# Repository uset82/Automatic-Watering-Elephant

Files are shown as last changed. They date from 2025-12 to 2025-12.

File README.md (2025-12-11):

# 🐘 Automatic Watering Elephant





> A dual-microcontroller autonomous plant watering system with a rotating table mechanism

**Course:** ADA525 - HW/SW System Design (Western Norway University of Applied Sciences)  
**Author:** Carlos Carpio  
**Date:** December 2025

---

## 📋 Overview

The **Automatic Watering Elephant** is an IoT plant care system that autonomously waters two avocado plants using a rotating table mechanism. It features a decorative elephant figurine with a detachable "hat" that houses the sensor electronics.

### ✨ Features

- 🔄 **Rotating table** with 3D-printed gear mechanism
- 🌡️ **Environmental monitoring** (temperature, humidity, soil moisture)
- 📺 **OLED display** for real-time status
- 🎮 **Position learning** - set plant positions with buttons
- 💧 **Automatic watering** with pump control
- 📊 **Web-based serial plotter** for signal visualization

---

## 🏗️ Architecture

```
┌─────────────────────┐     GPIO Signals      ┌─────────────────────┐
│   RP2350-Zero       │◄────────────────────►│    Arduino Uno      │
│   "The Brain"       │   TABLE_READY        │    "The Muscle"     │
│                     │   WATER_DONE         │                     │
│  • DHT11 Sensor     │                      │  • Stepper Motor    │
│  • Soil Moisture    │                      │  • Pump Relay       │
│  • OLED Display     │                      │  • Button Controls  │
└─────────────────────┘                      └─────────────────────┘
```

---

## 🛠️ Hardware Requirements

| Component | Quantity | Purpose |
|---|---|---|
| Arduino Uno | 1 | Motor & pump control |
| RP2350-Zero | 1 | Sensors & display |
| 28BYJ-48 Stepper | 1 | Table rotation |
| ULN2003 Driver | 1 | Stepper driver |
| SSD1306 OLED | 1 | Status display |
| DHT11 | 1 | Temperature/humidity |
| Soil Moisture Sensor | 1 | Soil monitoring |
| 5V Relay Module | 1 | Pump control |
| Mini Water Pump | 1 | Water delivery |
| Push Buttons | 3 | User controls |

---

## 📁 Project Structure

```
mesarota/
├── rotatingTable/          # Arduino Uno firmware
│   ├── src/main.cpp        # Motor, buttons, pump control
│   └── platformio.ini      # PlatformIO config
│
├── elefante/               # RP2350-Zero firmware  
│   ├── src/main.cpp        # Sensors, OLED, communication
│   └── platformio.ini      # PlatformIO config
│
├── PLOTTER ELEFANTE/       # Web-based serial plotter
│   ├── src/main.js         # Dual-port serial connection
│   ├── index.html          # UI layout
│   └── package.json        # Node dependencies
│
├── WIRING_GUIDE.md         # Detailed wiring instructions
└── README.md               # This file
```

---

## 🚀 Getting Started

### Prerequisites

- [PlatformIO](https://platformio.org/install) (VS Code extension recommended)
- [Node.js](https://nodejs.org/) (for the plotter)

### Installation

1. **Clone the repository:**
   ```bash
   git clone https://github.com/YOUR_USERNAME/automatic-watering-elephant.git
   cd automatic-watering-elephant
   ```

2. **Upload Arduino firmware:**
   ```bash
   cd rotatingTable
   pio run --target upload
   ```

3. **Upload RP2350 firmware:**
   ```bash
   cd ../elefante
   pio run --target upload
   ```

4. **Run the serial plotter (optional):**
   ```bash
   cd "../PLOTTER ELEFANTE"
   npm install
   npm run dev
   ```

---

## 🎮 Usage

### Position Learning Mode

1. **Power on** both controllers
2. **Hold Button A** → Rotate table clockwise
3. **Click Button A** → Save Position A (LED blinks 2x)
4. **Hold Button B** → Rotate table counter-clockwise
5. **Click Button B** → Save Position B (LED blinks 3x)

### Automatic Watering Cycle

After both positions are saved:
1. Table moves to **Position A** → Waters for 3 seconds
2. Table moves to **Position B** → Waters for 3 seconds
3. System enters **Sleep Mode**

### Reset

Press the **Reset Button** anytime to restart position learning.

---

## 📊 Serial Plotter

The web-based plotter displays real-time sensor data:

- **Temperature** (°C)
- **Humidity** (%)
- **Soil Moisture** (ADC)
- **Motor Position** (degrees)
- **Pump Status** (ON/OFF)

Access at `http://localhost:5173` after running `npm run dev`.

---

## 📷 Gallery

*Add images of your project here!*

---

## 📄 License

This project is open source and available under the [MIT License](LICENSE).

---

## 🙏 Acknowledgments

- **Professor Frikk Fossdal** - Course instructor & [Read Serial Plot tool](https://experiment.frikkfossdal.com/)
- **Western Norway University of Applied Sciences** - ADA525 Course
- **MakerWorld** - Image-to-3D tool for elephant figurine

---

*Made with ❤️ for ADA525 HW/SW System Design*

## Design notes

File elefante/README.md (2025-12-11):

# RP2350-Zero - Sensor Hub & Display

This firmware handles environmental sensors (DHT11, soil moisture) and the OLED display.

## Hardware Connections

| Pin | Function |
|-----|---|
| GP4 | OLED SDA |
| GP5 | OLED SCL |
| GP6 | DHT11 Data |
| GP10 | TABLE_READY ← Arduino (via voltage divider!) |
| GP11 | WATER_DONE → Arduino |
| GP26 | Soil Moisture Sensor (ADC) |

## Build & Upload

```bash
cd elefante
pio run --target upload
```

> ⚠️ If upload fails, hold BOOTSEL while plugging in USB.

## Serial Output (115200 baud)

Outputs: `Temp: 25.5 Humidity: 45 Pot: 2100 Motor: 0 OFF`

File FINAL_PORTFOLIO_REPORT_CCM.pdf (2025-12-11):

## Automatic Plant Watering Elephant with Rotating Table

## ADA525 Final Portfolio Report

Author: Carlos Carpio Date: December 2025 Institution: HVL - Western Norway University of Applied Sciences Course: ADA525 - Advanced Data Acquisition

## Introduction

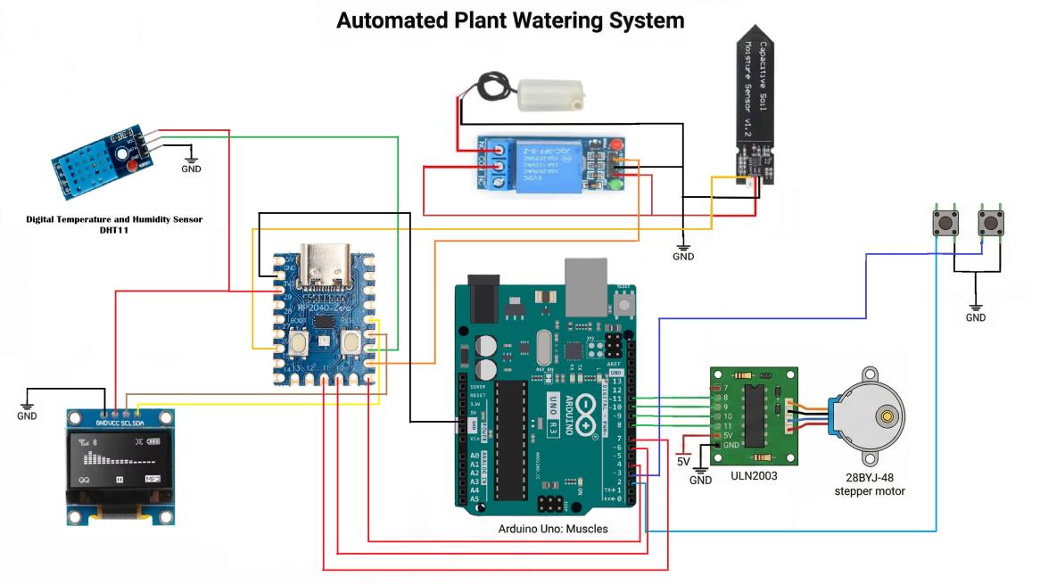
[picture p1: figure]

Visualization of the Automatic Watering Elephant project, showing the integration of nature and technology in a home plant care system.

Q0. Project Description

ELEPHANT AND DETACHABLE HAT CONCEPT

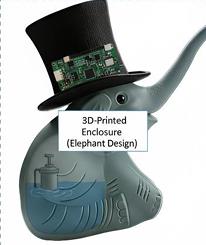
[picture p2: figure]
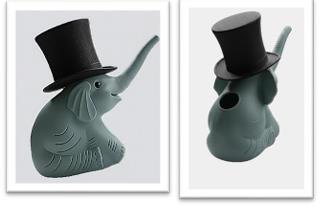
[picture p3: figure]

Figure 1: Concept art for the “Watering Elephant” design, featuring a decorative elephant figurine with a detachable hat that houses the electronics. The playful design makes the functional watering system blend naturally into a home environment. Generated using Google Gemini AI, nanoBanana.
The Automatic Watering Elephant is a dual-microcontroller plant care system that autonomously waters two avocado plants from Peruvian seeds using a rotating table mechanism. The system is designed to solve a real problem: maintaining healthy plants while traveling or during busy periods.
Why I wanted to make it: Growing avocado plants from seed requires consistent moisture levels. After losing several promising seedlings to irregular watering during travel, I was motivated to create a system that could reliably care for my plants without daily intervention. The project also presented an exciting opportunity to integrate digital fabrication, embedded systems, and inter-device communication.
Key Features:
1. Dual-Controller Architecture: RP2350-Zero handles sensing and decision-making (“Brain”), Arduino Uno controls mechanical rotation (“Muscles”)
2. Single Sensor for Multiple Plants: A rotating table brings each plant to the watering position, optimizing hardware usage
3. Capacitive Soil Moisture Sensing: Monitors soil moisture with 12-bit ADC resolution
4. Environmental Monitoring: DHT11 sensor tracks temperature and humidity
5. Pendulum Motion: The table swings back and forth (not continuous rotation) to prevent cable tangling
6. Flexible Position Learning: User can set plant positions in any order using teach-mode buttons
7. OLED Display: Real-time status visualization

Project Evolution Timeline

This project evolved through multiple phases during the ADA525 course:

Phase | Date | Focus | Key Learning
Initial Concept | Sep-Oct 2025 | Single-plant Arduino prototype | Basic pump control, sensor reading
Intermediate Report | Nov 2025 | RP2350-only design with rotating table | Power management challenges, motor interference
Final System | Dec 2025 | Dual-controller architecture | Inter-MCU communication, voltage level shifting

Evolution Highlights:
- Started with a simple Arduino-only watering system for one plant
- Teacher feedback pushed for more complexity → added mechanical rotation
- Power instability in RP2350-only design led to dual-controller architecture
- Cable tangling issue led to pendulum motion innovation
- Component failures taught importance of quality parts and debugging methodology The final system represents the culmination of lessons learned from each iteration, where early failures directly informed the robust design choices in the production version.
Q1. Core Workflow

The system workflow operates as follows:
User Interaction:
1. User powers on the system
2. LED illuminates indicating Learning Mode
3. User HOLDS Button A/B to manually rotate table to first plant position
4. User CLICKS to save position (LED blinks 3×)
5. User moves to second plant and CLICKS to save (LED blinks 5×)
6. System enters autonomous Run Mode

Sensing and Processing:

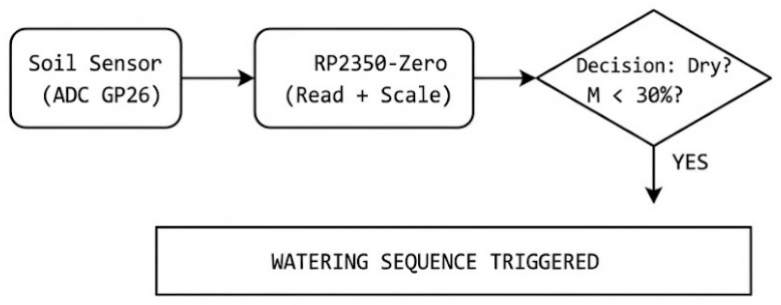
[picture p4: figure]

System Response (Handshake Protocol - Modified):
1. RP2350 sets WATER_SIGNAL = HIGH → Arduino receives on Pin 4 (Trigger)
2. Arduino rotates table to Plant 1
3. Arduino activates pump (Pin 12) for 3 seconds
4. Arduino rotates to Plant 2
5. Arduino activates pump (Pin 12) for 3 seconds
6. System enters sleep mode (waiting for next trigger or reset)

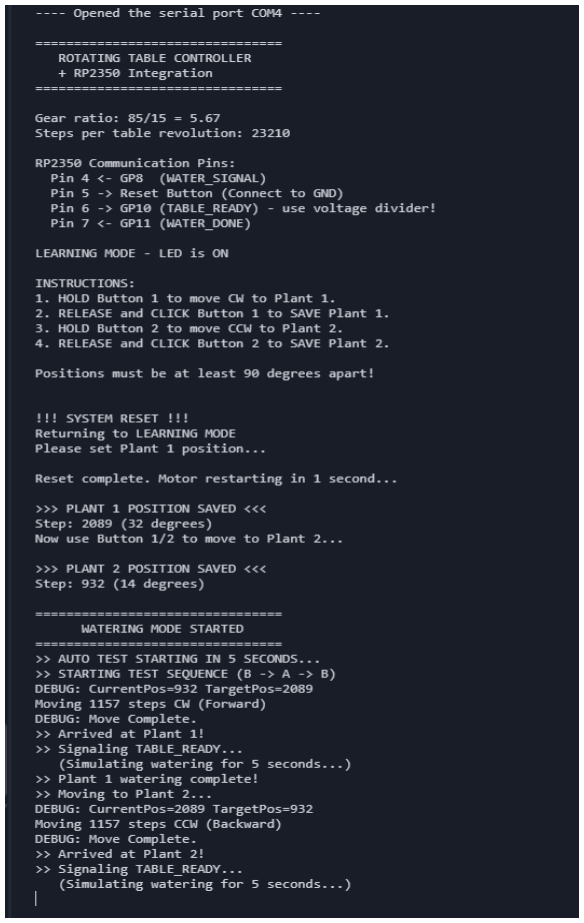
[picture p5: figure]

Figure 2: Screenshot of the Arduino Serial Monitor during a complete watering cycle. The output demonstrates the flexible position learning system. The users can set positions in any order (A→B or B→A) depending on the motor’s starting position. After both positions are saved (with LED blink feedback), the simulation sequence automatically begins: the table moves to Position A, waters for 3 seconds, moves to Position B, waters again, and enters sleep mode.
NOTE: Pump control was moved from RP2350 to Arduino (Pin 12) to overcome GPIO latching issues on the prototype board. The RP2350 retains the role of “Brain” (Sensing), while Arduino acts as “Muscle” (Motion & Action).

## System Implementation

Digital Fabrication Focus
Q2. CAD & 3D Printing Integration
The Elephant Figurine Evolution:
From idea to 3D modeling, I started by generating the elephant concept image in Google Gemini AI and then used MakerWorld’s MakerLab “Image to 3D” tool to turn it into a 3D mesh. I first imported this mesh into Fusion 360 to inspect and split the geometry, but the dense mesh was difficult to handle there, so I moved the project to Blender.
In Blender, I used the Boolean modifier to subtract an inner shape from the elephant, creating a clean internal cavity and turning the solid model into a hollow “elephant kettle” that could house the electronics. Blender also helped me fix errors and rebuild the imperfections from the AI-generated mesh. In the end, I spent more time repairing than building, but that taught me valuable lessons as an engineer about real-world challenges and different approaches to problem-solving.

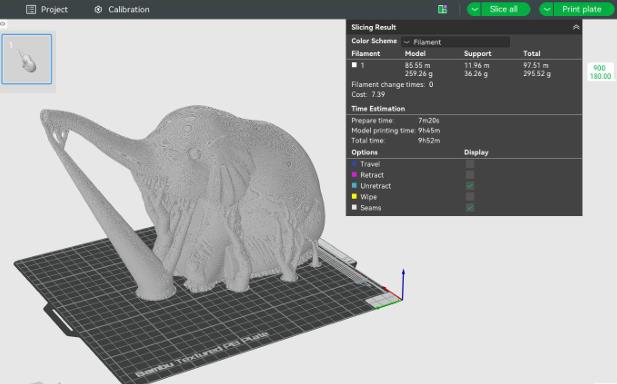
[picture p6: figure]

Blender Mesh Repair Process

Figure 3: When I import a model from Blender into Bambu Studio it often shows up much smaller, because the two programs use different unit scales. If I do not fix the size right away, later edits and slicing go wrong, and I kept running into the same error after shrinking the model. Before scaling to real size I first cut the hat away from the elephant in Bambu Studio, so I can scale and align each part separately with better precision.

The Rotating Table Mechanism:
The rotating table mechanism required custom gears designed in CAD and manufactured using 3D printing:

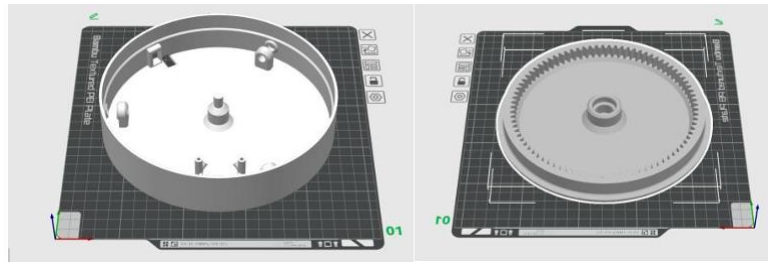
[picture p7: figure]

3D Model of Rotating Table

Figure 4: CAD model of the rotating display table designed in Fusion 360. The design features an integrated ring gear mechanism that meshes with a small driver gear attached to the stepper motor, providing smooth and precise rotation.
Design Evolution:
Version | Design | Issue | Solution
V1 | Single gear, direct drive | Insufficient torque | Added gear reduction
V2 | 15:85 tooth ratio | Gear slippage | Redesigned tooth profile
V3 (Final) | Optimized spur gear + ring gear | N/A | Successful

COMPONENTS DESIGNED AND PRINTED:
- Small Driver Gear: 15-tooth spur gear (orange PLA), press-fit to motor shaft

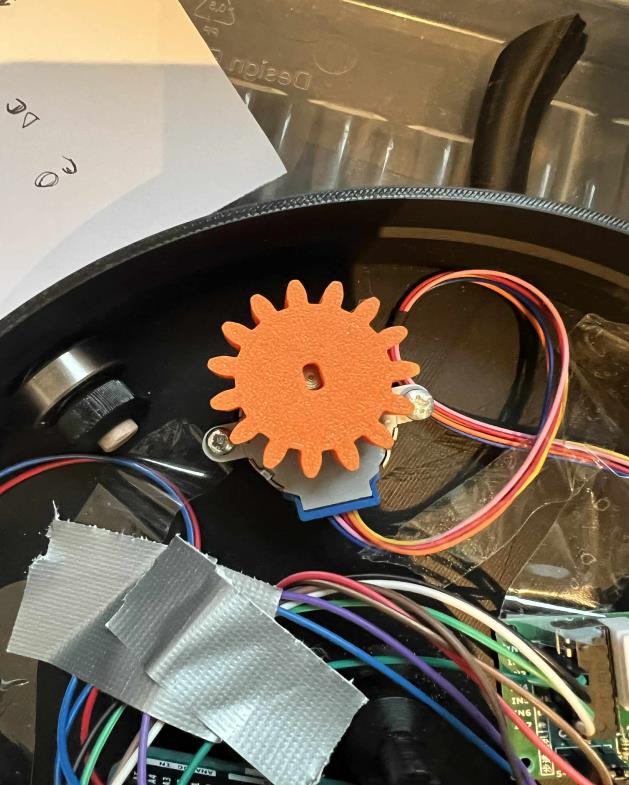
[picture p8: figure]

Figure 5: The 15-tooth driver gear printed in orange PLA, designed to press-fit onto the 28BYJ-48 motor’s asymmetric shaft.

- Large Ring Gear: 85-tooth internal ring gear (white PLA), integrated into table base

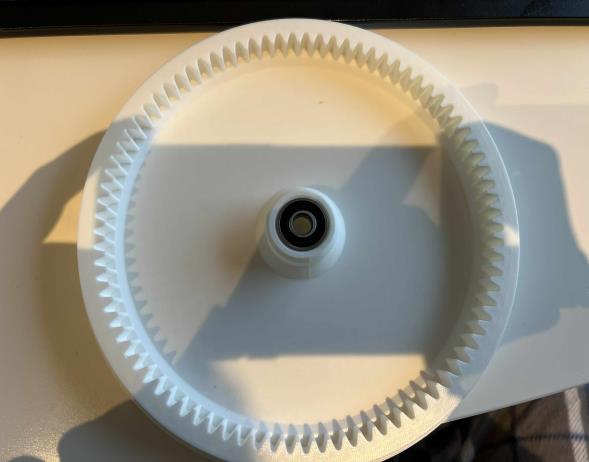
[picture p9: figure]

Figure 6: The 85-tooth ring gear printed in white PLA, which forms the base of the rotating table and provides the 5.67:1 gear reduction.

Gear Ratio Calculation:

Gear Ratio =

85
15 = 5.67

This provides:
- Speed reduction: Motor runs 5.67× faster than table rotation
- Torque multiplication: Table receives 5.67× motor torque
- Precision: 23,210 steps per table revolution (0.0155° resolution) Tools Used:
- Fusion 360 for gear modeling
- Cura slicer for print preparation
- Creality Ender 3 printer (0.2mm layer height, 20% infill)
Q3. Fabrication Challenges
Challenge 1: Gear Backlash Early prints exhibited significant play between meshing teeth, causing positioning inaccuracy.
Solution: Adjusted tooth clearance in CAD by reducing the module parameter by 0.1mm. Required 3 print iterations to achieve acceptable fit.
Challenge 2: Motor Shaft Coupling The 28BYJ-48 motor has an asymmetric shaft that was difficult to model accurately.
Solution: Created a test coupler with incrementally different hole shapes, then updated the main gear design based on best-fit results.
Challenge 3: Ring Gear Warping The large ring gear (120mm diameter) exhibited warping during printing due to uneven cooling.
Solution: Enabled heated bed adhesion rim and printed at reduced speed (30mm/s) for first 5 layers.

Physical Computing Focus
Q4. Hardware Integration

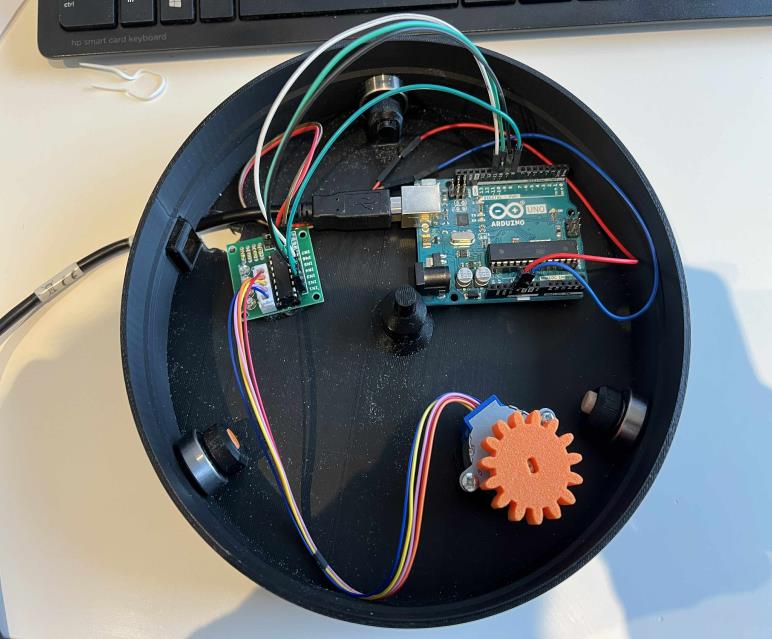
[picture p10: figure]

Internal Electronics Layout

Figure 7: Internal view of the electronics assembly showing the RP2350-Zero microcontroller, relay module, and sensor connections. The compact layout fits within the elephant figurine’s detachable hat.
The system incorporates multiple physical computing elements across two microcontrollers:
RP2350-Zero (Sensor Hub & Brain):
Component | Purpose | Connection | Justification
Capacitive Soil Sensor | Moisture detection | GP26 (ADC) | Corrosion-resistant, long-term reliability
DHT11 | Temp/Humidity | GP6 (Digital) | Low cost, sufficient accuracy for plant care
SSD1306 OLED | Status display | I2C (GP4/5) | Low power, always-on visibility
Relay Module | Pump control | GP7 | Isolates high-current load from MCU

Arduino Uno (Motor Controller + Pump):

Component | Purpose | Connection | Justification
28BYJ-48 Stepper | Table rotation | Pins 8-11 | High torque, low cost, easy control
ULN2003 Driver | Current amplification | Pins 8-11 | Matches motor requirements exactly
Push Buttons ×3 | Position A, B, Reset | Pins 2, 3, 5 | Simple, reliable user input
Relay Module | Pump control | Pin 12 | Arduino-direct control for reliability

Final Implementation: During integration testing, RP2350 GPIO issues led to moving pump control directly to Arduino Pin 12. This simplified the system and improved reliability while maintaining all functionality.

OLED Display

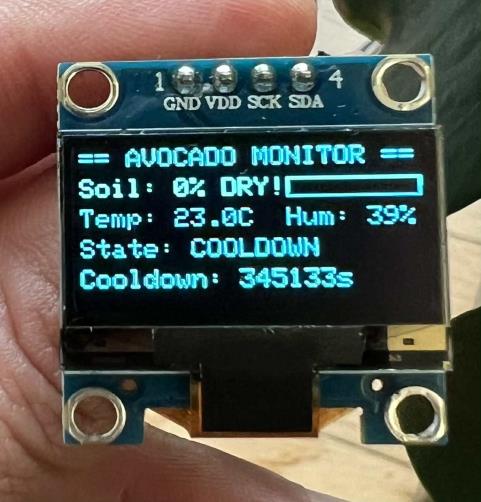
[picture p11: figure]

Figure 8: The SSD1306 OLED display (128×64 pixels) showing real-time system status. The display provides immediate visual feedback including current state (Idle/Watering), temperature, humidity, and soil moisture readings. Connected via I2C to the RP2350-Zero (GP4/GP5), this low-power display remains always-on for easy monitoring.
Key Code Snippet - Stepper Control:

// Half-step sequence for smoother motion (8 phases) const int halfStepSequence[8][4] = {
{1,0,0,0}, {1,1,0,0}, {0,1,0,0}, {0,1,1,0}, {0,0,1,0}, {0,0,1,1}, {0,0,0,1}, {1,0,0,1}
};

void stepMotor(bool clockwise) {
stepPhase += clockwise ? 1 : -1;
if (stepPhase >= 8) stepPhase = 0;
if (stepPhase < 0) stepPhase = 7;

digitalWrite(IN1, halfStepSequence[stepPhase][0]);

// ... IN2, IN3, IN4
delay(stepDelay); // 1ms for maximum speed }
Q5a. Data Acquisition Strategy
Soil Moisture Calibration: The capacitive sensor outputs analog voltage inversely proportional to moisture. Calibration was performed by:
1. Recording ADC value in air: R_dry ≈ 3000
2. Recording ADC value in water: R_wet ≈ 1200
3. Applying linear interpolation:

M = 100 × (1 −
R − Rwet

Rdry − Rwet)

Setting the watering threshold at 30% moisture proved optimal after testing. Lower thresholds (20%) caused stress-visible wilting; higher thresholds (40%) led to overwatering and root rot risk. Avocado plants (Persea americana) prefer to dry out between waterings, so a 4-5 day cooldown period between watering cycles was implemented to prevent overwatering.

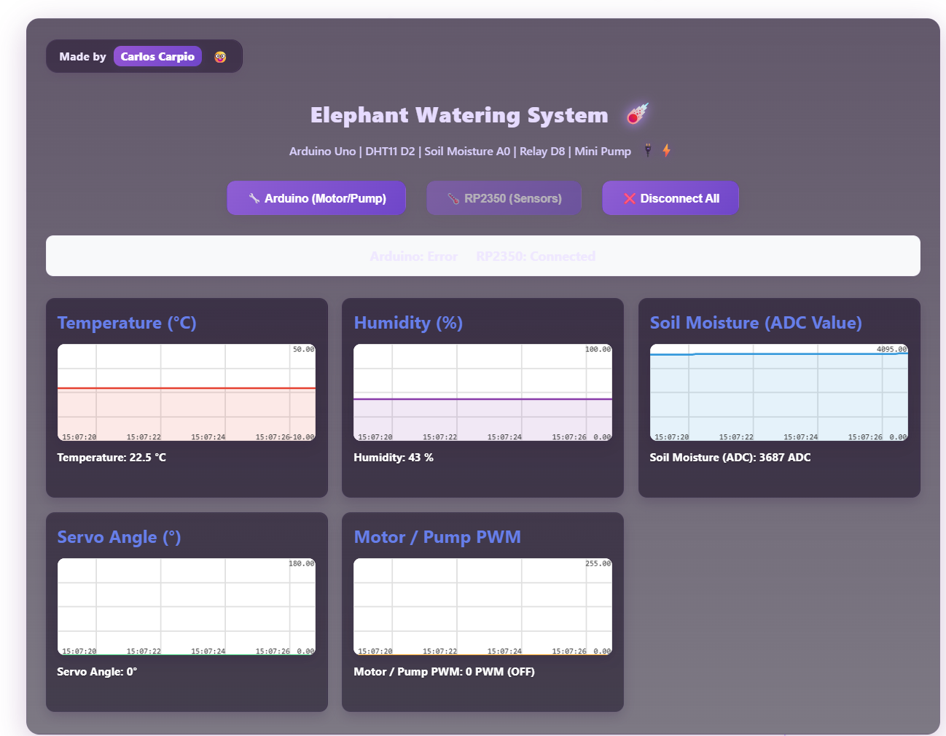
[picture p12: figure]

Sensor Data Graph

Figure 9: Real-time visualization of sensor data using the "Read Serial Plot" tool (https://experiment.frikkfossdal.com/content/guides/readserial_plot.md) created by Professor Frikk Fossdal. This graph demonstrates how the soil moisture ADC values can be monitored live during development and calibration. The tool streams serial output directly into a graphical interface, making it easy to identify sensor behavior patterns and set appropriate thresholds.
Position Tracking: The Arduino maintains a step counter that wraps at 23,210 (one full revolution). When saving positions, the current step value is stored, enabling precise return navigation using the shortest-path algorithm.
Q5b. Integration Challenges
Challenge 1: Voltage Level Mismatch The RP2350 operates at 3.3V logic; Arduino Uno at 5V. Direct connection from Arduino Pin 6 to RP2350 GP10 risked damaging the Pico. Solution: Implemented voltage divider (1kΩ + 2kΩ):

Vout = 5V ×

2000
3000 = 3.33V

Voltage Divider Wiring Diagram:

┌─────────────────────────────────────┐
│ | VOLTAGE DIVIDER | │
└─────────────────────────────────────┘
ARDUINO UNO | RP2350-ZERO
┌───────────┐ | ┌───────────┐
│ | │ | │ | │
│ | Pin 6 | │────[1kΩ]────┬────[2kΩ]──── │ | GND | │
│ (OUTPUT) │ | │ | │ | │
│ | │ | │ | │ | │
│ | GND | │─────────────┼──────────────│ | GND | │
│ | │ | │ | │ | │
└───────────┘ | │ | │ | GP10 | │
│ | │ (INPUT) │
└──────────────│ | │
└───────────┘
CAUTION. Never connect Arduino 5V outputs directly to RP2350 GPIO pins! The RP2350 GPIO is rated for 3.3V maximum. Connecting 5V directly will damage or destroy the pin. Always use a voltage divider for signals going FROM Arduino TO RP2350.
Challenge 2: Button Debouncing Initial implementation registered multiple button presses due to mechanical bounce.
Solution: Added 200ms debounce delay and separate timers for position buttons vs. reset button.
Challenge 3: Motor Speed vs. Torque Trade-off Too fast (1ms delay): Motor skipped steps under load. Too slow (5ms delay): Watering cycle took too long.
Solution: Settled on 1ms delay after testing showed the gear reduction provided sufficient torque even at maximum speed.
Challenge 4: Power Supply Voltage Drop (Critical) When both motors (water pump and stepper motor) were connected to the same power supply, the stepper motor stopped working intermittently. Even after adding a 2200μF decoupling capacitor and testing with an L293D driver, the problem persisted.
Root Cause Analysis:
- The water pump draws a large inrush current when starting
- This caused the shared power rail voltage to drop significantly
- The L293D driver adds an additional 1.2-2V voltage drop
- Combined effect: stepper driver received insufficient voltage to function Solution: Separated the system into two independent 9V battery supplies:

Battery | Powers | Reason
9V Battery #1 | Arduino Uno + Stepper Motor + ULN2003 | Isolated motor power prevents interference
9V Battery #2 | RP2350 + Pump + Sensors (OLED, DHT11) | Pump surges don’t affect logic circuits

Critical: Both batteries share a common ground to maintain signal integrity for the handshake protocol.
This dual-battery configuration completely eliminated the voltage instability issues.

Challenge 5: Defective Low-Cost Hardware (The “AliExpress Lesson”)

I bought a very cheap RP2350 Zero board from AliExpress to use as the main controller. It behaved unpredictably when driving motors, even with simple code.

- Symptoms: GPIO pins got stuck LOW, uploads worked but the program did not run, and motor control was unstable.
- Tried fixes: Added big decoupling capacitors, used separate power supplies, and rewrote the code over two very long debugging days.
- Result: The board was simply not reliable for heavy work, most likely due to poor internal power design or low manufacturing quality.

Lesson learned: Cheap boards may save money but can cost many hours of debugging. The dual controller setup saved the project, since the reliable Arduino could take over when the “smart” but weak RP2350 Zero failed.

Integration and Synthesis
Q6. Mechanical + Electronic Integration

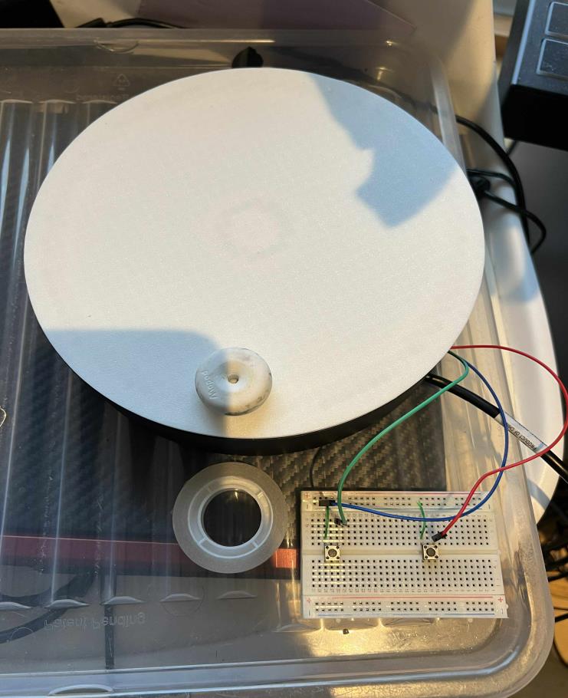
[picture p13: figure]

Final Assembled Rotating Table

Figure 10: The fully assembled rotating table mechanism showing the 3D-printed ring gear, stepper motor mount, and plant positioning area. The pendulum motion design allows back-and-forth movement without cable tangling.
Integrating the 3D-printed gears with the electronic control system required careful consideration:
Physical Constraints:
- Motor mount had to align the gears within 0.5 mm
- Wires had to be routed away from moving parts
- The sensor on the table needed flexible cables

These limits killed my original idea of 360 degree continuous rotation, because the cables kept tangling in early tests. I redesigned the system to use a pendulum style motion instead and rewrote the state machine logic, which made the whole setup more robust.

Design Considerations:
1. Cable Management: The pendulum motion (back-and-forth) was specifically chosen to prevent water hose and cable tangling that would occur with continuous rotation
2. Gear Alignment: Added adjustment slots in motor mount to fine-tune gear mesh after assembly
3. Weight Distribution: Positioned electronics below the table to lower center of gravity

Q7. Iterative Process

Prototype Version 1 - Single Plant (Too Simple):
- Arduino Uno only, no rotating table
- Single plant with direct pump connection
- Manual button trigger for watering
- Feedback: Teacher said “too simple” - needed more complexity to demonstrate embedded systems skills
- Decision: Add mechanical rotation to water multiple plants with single pump Prototype Version 2 - Integrated Elephant (RP2350 Only):
- RP2350-Zero as the sole controller (no Arduino)
- All components housed inside the elephant figurine’s hat
- RP2350 directly driving stepper motor via ULN2003
- Capacitive soil sensor for moisture detection
- Water pump controlled via relay
- Problem: Power instability when pump and stepper shared supply - stepper stopped working during pump activation
- Problem: Even with 2200μF capacitor and L293D driver, voltage drops persisted
- Decision: Split system into two controllers to isolate motor power domains Prototype Version 3 - Final Dual-Controller System:
- Separated into two controllers: RP2350 (Brain) + Arduino Uno (Muscles)
- Dual 9V battery power supply
- Digital handshake protocol for communication
- Pendulum motion to prevent cable tangling
- Flexible position learning (either button first)
- Full sensor suite: soil moisture, DHT11, OLED display

Major Challenge: Cheap Component Failures
A significant time delay occurred due to defective components purchased from low-cost suppliers:
Failed Component | Symptom | Resolution
Stepper Motor #1 | Erratic movement, missed steps | Replaced
Stepper Motor #2 | Coil burned, no response | Replaced
DHT11 Sensor | Constant “NaN” readings | Replaced with known-good unit
Dupont Cables | Intermittent connections | Replaced with higher quality cables
Lesson Learned: The time “saved” buying cheap components was lost debugging phantom failures. For future projects, I would invest in quality components from reputable suppliers, especially for critical actuators.
Major Integration Problem:
Issue: When the stepper motor activated, electrical noise caused false readings on the soil moisture ADC, triggering phantom watering cycles.
Diagnosis: Used oscilloscope to observe voltage spikes on the power rail during motor steps. The ULN2003 driver’s inductive kickback was coupling into the shared ground.

Critical Evaluation and Future Scope
Q9. System Evaluation
Strengths:
- Modular dual-controller architecture enables independent testing
- Pendulum motion solves cable management elegantly
- Flexible position learning accommodates various plant arrangements
- Single sensor for multiple plants optimizes cost
Limitations:
- No persistent position storage (lost on power cycle)
- Fixed watering duration regardless of pot size
- Single moisture sensor assumes identical soil for both plants
- No remote monitoring capability

Q10. Future Improvements
Improvement | Benefit | Complexity
EEPROM position storage | Survives power cycle | Low
Custom PCB Shield | Eliminates cable mess & improves reliability | Medium
WiFi (ESP32) upgrade | Remote monitoring & control | Medium
Per-plant moisture sensors | Individualized watering | Medium
Water reservoir level sensor | Low-water alerts | Low
Machine learning moisture prediction | Anticipate watering needs | High
Solar power integration | Off-grid operation | Medium
Advancement Priority: With more time, I would first add EEPROM storage for positions (simple code change) and design a Custom PCB to replace the breadboard wiring, ensuring a cleaner and more durable system. Then, I would upgrade to ESP32 for WiFi capabilities.

## Appendix

A. Pin Configuration Summary

RP2350-Zero:

GP26 ← Soil Sensor (ADC)
GP6 | ← DHT11 Data
GP4 | → OLED SDA (I2C)
GP5 | → OLED SCL (I2C)
GP7 | → Relay Control
GP8 | → WATER_SIGNAL (to Arduino Pin 4)
GP10 ← TABLE_READY (from Arduino Pin 6, via voltage divider) GP11 → WATER_DONE (to Arduino Pin 7)
Arduino Uno:

Pin 2 ← Button A (Position)
Pin 3 ← Button B (Position)
Pin 4 ← WATER_SIGNAL (from RP2350 GP8) Pin 5 ← Button Reset
Pin 6 → TABLE_READY (to RP2350 GP10) Pin 7 ← WATER_DONE (from RP2350 GP11) Pin 8 → Motor IN1
Pin 9 → Motor IN2
Pin 10 → Motor IN3
Pin 11 → Motor IN4
B. References
1. Arduino Reference. (2025). Arduino Language Reference. https://www.arduino.cc/reference/en/
2. Raspberry Pi Foundation. (2024). RP2350 Datasheet.
3. 28BYJ-48 Stepper Motor Datasheet
4. ULN2003 Darlington Transistor Array Datasheet
5. DHT11 Humidity & Temperature Sensor Datasheet
6. PlatformIO Documentation. https://docs.platformio.org/

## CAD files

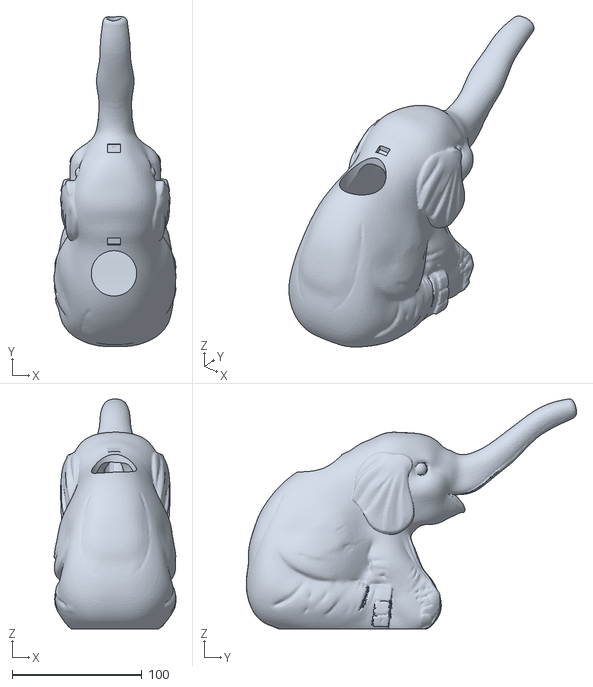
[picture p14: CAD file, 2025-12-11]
3Dmodelling/2 elephants decimated hole resizing trunk and hole fix.stl
93.9 x 254.8 x 177.3

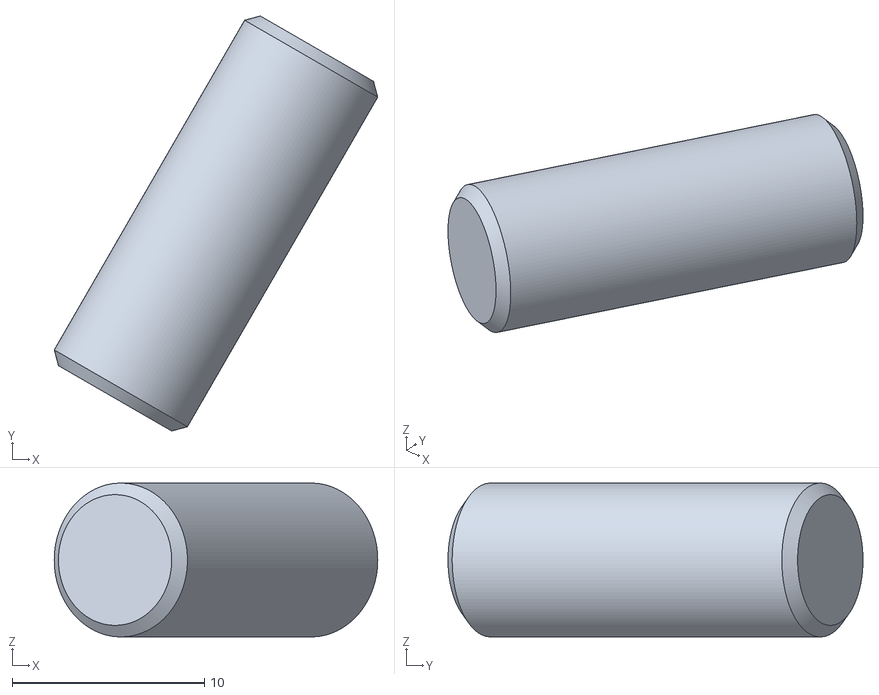
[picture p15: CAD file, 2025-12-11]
3Dmodelling/rotating table/Pin_.stl
16.8 x 21.6 x 8.00

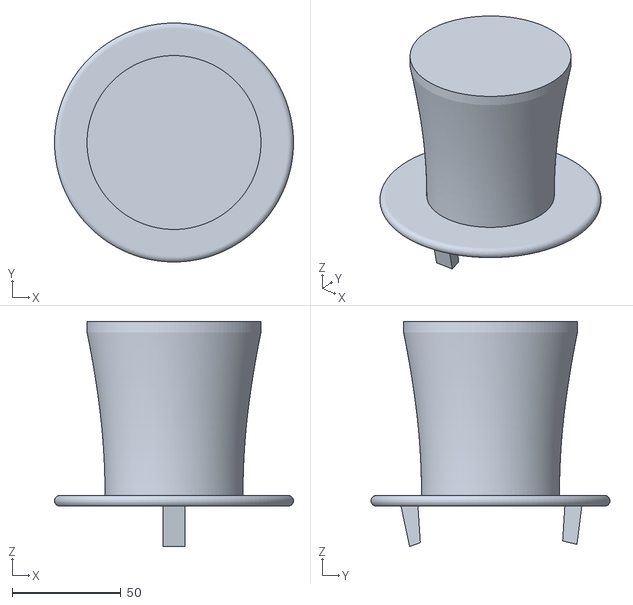
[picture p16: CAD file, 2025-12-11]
3Dmodelling/elephant hat remake.stl
110.0 x 109.9 x 103.5

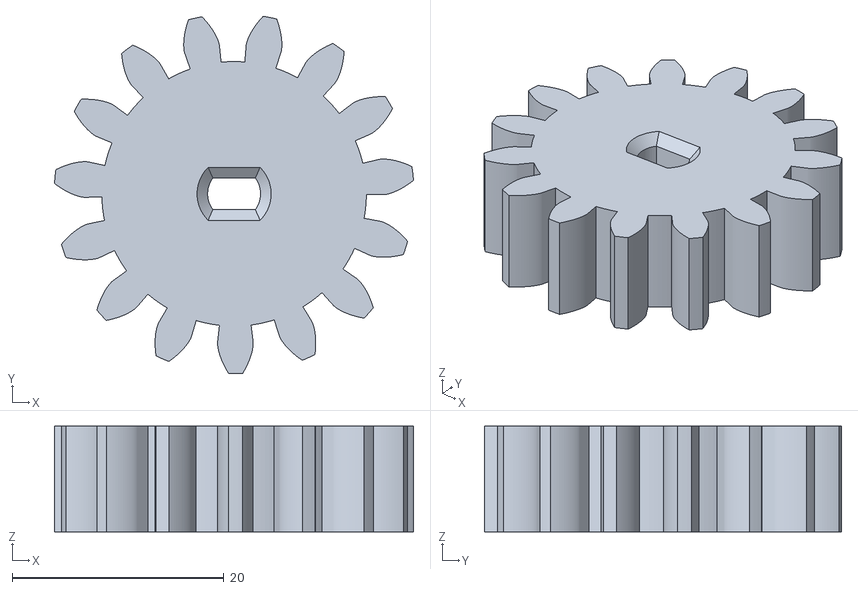
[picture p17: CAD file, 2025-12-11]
3Dmodelling/rotating table/Motor_Gear.stl
33.9 x 33.8 x 10.0

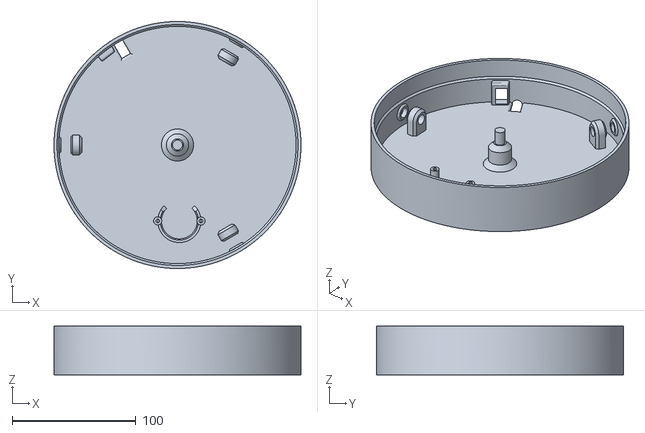
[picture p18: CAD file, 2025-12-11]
3Dmodelling/rotating table/Base.stl
200.0 x 200.0 x 39.5

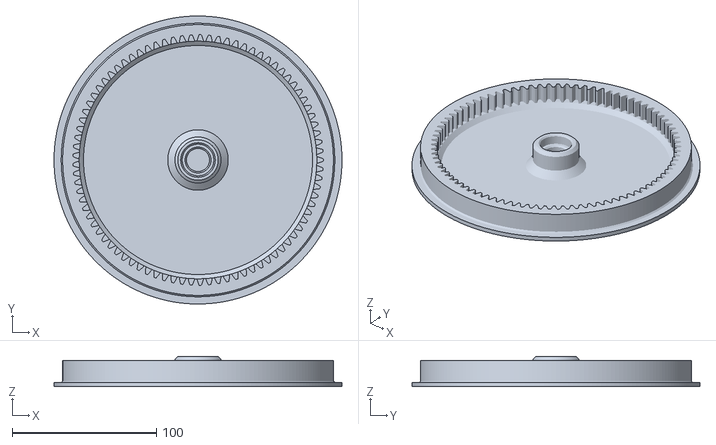
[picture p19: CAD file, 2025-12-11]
3Dmodelling/rotating table/Top_plate_.stl
200.0 x 200.0 x 21.0

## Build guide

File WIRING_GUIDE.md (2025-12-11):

# 🌱 Automatic Plant Watering System - Wiring Guide

## System Overview

This system combines:
- **RP2350-Zero**: Brain - monitors soil moisture, controls pump, communicates with Arduino
- **Arduino Uno**: Muscles - controls rotating table stepper motor
- **2 Avocado Plants** on rotating table (same pot size, same germination date)
- **1 Soil Sensor** shared for both plants (identical conditions = same watering needs)

## Power Rails

| Rail | Voltage | Components |
|---|---|---|
| Logic Rail | 3.3V | RP2350, OLED, DHT11, Soil Sensor |
| Motor Rail | 5V | Arduino Uno, Stepper Motor, Relay VCC |
| Pump Rail | 5-6V External | Water Pump (via relay) |

⚠️ **IMPORTANT**: Common GND between ALL components!

---

## RP2350-Zero Pinout

### Sensors
| Pin | Function | Component |
|-----|---|---|
| GP26 (ADC0) | Soil Moisture | Capacitive sensor (shared for both plants) |
| GP6 | DHT11 DATA | Temperature/Humidity sensor |
| GP4 | I2C SDA | OLED Display |
| GP5 | I2C SCL | OLED Display |

### Control
| Pin | Function | Component |
|-----|---|---|
| GP7 | Relay IN | Pump control (active LOW) |

### Arduino Communication
| RP2350 Pin | Direction | Arduino Pin | Signal |
|---|---|---|---|
| GP8 | OUTPUT → | Pin 4 | WATER_SIGNAL |
| GP10 | ← INPUT | Pin 6 | TABLE_READY |
| GP11 | OUTPUT → | Pin 7 | WATER_DONE |
| GND | ↔ | GND | Common Ground |

---

## Arduino Uno Pinout

### Motor Control (28BYJ-48 Stepper via ULN2003)
| Pin | Function |
|-----|---|
| Pin 8 | Motor IN1 |
| Pin 9 | Motor IN2 |
| Pin 10 | Motor IN3 |
| Pin 11 | Motor IN4 |

### Position Buttons
| Pin | Function |
|-----|---|
| Pin 2 | Button 1 - Set Plant 1 Position |
| Pin 3 | Button 2 - Set Plant 2 Position |

### RP2350 Communication
| Arduino Pin | Direction | RP2350 Pin | Signal |
|---|---|---|---|
| Pin 4 | ← INPUT | GP8 | WATER_SIGNAL |
| Pin 6 | OUTPUT → | GP10 | TABLE_READY |
| Pin 7 | ← INPUT | GP11 | WATER_DONE |
| GND | ↔ | GND | Common Ground |

---

## ⚠️ Voltage Level Shifting

The RP2350 uses **3.3V logic**, Arduino Uno uses **5V logic**.

### RP2350 → Arduino (3.3V to 5V)
✅ **Safe!** Arduino reads 3.3V as HIGH (threshold ~2.5V)
- GP8 → Pin 4 (direct connection OK)
- GP11 → Pin 7 (direct connection OK)

### Arduino → RP2350 (5V to 3.3V)
⚠️ **Needs voltage divider!** 5V will damage RP2350!

**TABLE_READY Signal (Pin 6 → GP10):**
```
Arduino Pin 6 ──[1K]──┬──[2K]── GND
                      │
                      └─── RP2350 GP10

Voltage at GP10 = 5V × (2K / (1K + 2K)) = 3.33V ✓
```

---

## Soil Moisture Sensor Wiring

Single capacitive soil moisture sensor (shared for both plants):
```
Sensor      RP2350
──────      ──────
VCC    →    3.3V
GND    →    GND
AOUT   →    GP26
```

---

## DHT11 Wiring

```
DHT11       RP2350
─────       ──────
VCC    →    3.3V
GND    →    GND
DATA   →    GP6 (internal pull-up enabled)
```

---

## OLED Display Wiring (SSD1306 128x64)

```
OLED        RP2350
────        ──────
VCC    →    3.3V
GND    →    GND
SDA    →    GP4
SCL    →    GP5
```

---

## Relay Module Wiring

```
Relay       RP2350          External Power
─────       ──────          ──────────────
VCC    →    5V (from Arduino or external)
GND    →    GND
IN     →    GP7

Relay NO    →    Pump +
Relay COM   →    External 5-6V +
Pump -      →    External GND
```

---

## Watering Sequence

```
1. RP2350 detects soil is dry (< 30% moisture)
2. RP2350 sets WATER_SIGNAL = HIGH
3. Arduino moves table to Plant 1 position
4. Arduino sets TABLE_READY = HIGH
5. RP2350 runs pump for 5 seconds
6. RP2350 sets WATER_DONE = HIGH (pulse)
7. Arduino sees WATER_DONE, moves to Plant 2 position
8. Arduino sets TABLE_READY = HIGH
9. RP2350 runs pump for 5 seconds
10. RP2350 sets WATER_DONE = HIGH (pulse)
11. Both plants watered! System enters 1 minute cooldown
```

### Signal Timing

| Signal | Duration | Purpose |
|---|---|---|
| WATER_SIGNAL | Entire watering cycle | Request watering for both plants |
| TABLE_READY | Until WATER_DONE pulse | Table is at plant position |
| WATER_DONE | 500ms pulse | Current plant watering complete |

---

## Setup Procedure

1. **Power on system** - Arduino starts in Learning Mode (LED ON)

2. **Set Plant 1 position:**
   - Wait for table to rotate to Plant 1
   - Press Button 1 (Pin 2)
   - LED blinks 3 times = Position saved

3. **Set Plant 2 position:**
   - Wait for table to rotate to Plant 2 (must be >90° from Plant 1)
   - Press Button 2 (Pin 3)
   - LED blinks 5 times = Position saved
   - System enters Watering Mode (LED OFF)

4. **Automatic operation:**
   - RP2350 monitors soil moisture
   - When soil is dry → water Plant 1 → water Plant 2 → cooldown
   - 1 minute cooldown between watering cycles

---

## Troubleshooting

| Symptom | Cause | Solution |
|---|---|---|
| Table doesn't move | No signal from RP2350 | Check GP8 → Pin 4 wire |
| RP2350 crashes | 5V on GP10 | Add voltage divider! |
| Pump doesn't run | TABLE_READY not seen | Check voltage divider output |
| Only Plant 1 watered | WATER_DONE not received | Check GP11 → Pin 7 wire |
| Soil always reads 0% | Sensor not in soil | Push sensor into soil |
| Soil always reads 100% | Wrong calibration | Adjust SOIL_DRY_VALUE/SOIL_WET_VALUE |

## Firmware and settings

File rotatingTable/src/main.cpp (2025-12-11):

#if defined(__has_include) && __has_include(<Arduino.h>)
#include <Arduino.h>
#elif !defined(__has_include) && defined(ARDUINO)
#include <Arduino.h>
#else
// Minimal Arduino stubs so clang/desktop parses without Arduino SDK
#include <chrono>
#include <thread>

#ifndef HIGH
#define HIGH 0x1
#endif
#ifndef LOW
#define LOW 0x0
#endif
#ifndef INPUT
#define INPUT 0x0
#endif
#ifndef OUTPUT
#define OUTPUT 0x1
#endif
#ifndef INPUT_PULLUP
#define INPUT_PULLUP 0x2
#endif
#ifndef LED_BUILTIN
#define LED_BUILTIN 13
#endif

inline void pinMode(int, int) {}
inline int digitalRead(int) { return HIGH; }
inline void digitalWrite(int, int) {}
inline void delay(unsigned long ms) {
  std::this_thread::sleep_for(std::chrono::milliseconds(ms));
}
inline unsigned long millis() {
  using namespace std::chrono;
  return static_cast<unsigned long>(
      duration_cast<milliseconds>(steady_clock::now().time_since_epoch())
          .count());
}

struct SerialMock {
  void begin(unsigned long) {}
  template <typename T> void print(const T &) {}
  template <typename T> void println(const T &) {}
  void println() {}
} Serial;
#endif

/*
  Rotating Table + RP2350 Pump Control

  SKIP SOIL SENSOR - Manual trigger after learning

  Arduino controls: Rotating table motor
  RP2350 controls: Pump (GP7)

  Communication:
  - Arduino Pin 6 -> RP2350 GP10 (TABLE_READY) - use voltage divider!
  - RP2350 GP11 -> Arduino Pin 7 (WATER_DONE)

  Flow:
  1. Learning Mode: Save positions A and B
  2. Simulation starts automatically after both saved
  3. Move to A -> signal TABLE_READY -> wait for WATER_DONE
  4. Move to B -> signal TABLE_READY -> wait for WATER_DONE
  5. Sleep
*/

// Motor pins
const int MOTOR_IN1 = 8;
const int MOTOR_IN2 = 9;
const int MOTOR_IN3 = 10;
const int MOTOR_IN4 = 11;

// Button pins
const int BUTTON_A = 2;
const int BUTTON_B = 3;
const int RESET_BTN = 5;

// PUMP CONTROL (direct from Arduino - bypassing RP2350)
const int PUMP_PIN = 12;                  // Relay control
const bool RELAY_ACTIVE_LOW = true;       // Most relay modules are active-LOW
const unsigned long PUMP_DURATION = 3000; // 3 seconds

// Half-step sequence
const int halfStep[8][4] = {{1, 0, 0, 0}, {1, 1, 0, 0}, {0, 1, 0, 0},
                            {0, 1, 1, 0}, {0, 0, 1, 0}, {0, 0, 1, 1},
                            {0, 0, 0, 1}, {1, 0, 0, 1}};
int stepPhase = 0;

// Position tracking
long currentPos = 0;
long positionA = -1;
long positionB = -1;

// Mode flags
bool learningMode = true;

void stepMotor(bool clockwise) {
  if (clockwise) {
    stepPhase++;
    if (stepPhase >= 8)
      stepPhase = 0;
    currentPos++;
  } else {
    stepPhase--;
    if (stepPhase < 0)
      stepPhase = 7;
    currentPos--;
  }

  digitalWrite(MOTOR_IN1, halfStep[stepPhase][0]);
  digitalWrite(MOTOR_IN2, halfStep[stepPhase][1]);
  digitalWrite(MOTOR_IN3, halfStep[stepPhase][2]);
  digitalWrite(MOTOR_IN4, halfStep[stepPhase][3]);
  delay(2);
}

void stopMotor() {
  digitalWrite(MOTOR_IN1, LOW);
  digitalWrite(MOTOR_IN2, LOW);
  digitalWrite(MOTOR_IN3, LOW);
  digitalWrite(MOTOR_IN4, LOW);
}

void moveToPosition(long target) {
  long stepsNeeded = target - currentPos;
  bool clockwise = stepsNeeded > 0;
  long absSteps = stepsNeeded > 0 ? stepsNeeded : -stepsNeeded;

  Serial.print("Moving ");
  Serial.print(absSteps);
  Serial.println(clockwise ? " steps CW" : " steps CCW");

  for (long i = 0; i < absSteps; i++) {
    stepMotor(clockwise);
  }
  stopMotor();
  Serial.println("Arrived!");
}

void pumpON() {
  digitalWrite(PUMP_PIN, RELAY_ACTIVE_LOW ? LOW : HIGH);
  Serial.println(">>> PUMP ON!");
}

void pumpOFF() {
  digitalWrite(PUMP_PIN, RELAY_ACTIVE_LOW ? HIGH : LOW);
  Serial.println(">>> PUMP OFF!");
}

void waterPlant() {
  Serial.println(">>> Starting pump for 3 seconds...");
  pumpON();

  // Blink LED while pumping
  for (int i = 0; i < 6; i++) {
    digitalWrite(LED_BUILTIN, i % 2);
    delay(500);
  }

  pumpOFF();
  Serial.println(">>> Watering complete!");
  digitalWrite(LED_BUILTIN, HIGH);
  delay(500);
}

void runSimulation() {
  Serial.println("");
  Serial.println("=============================");
  Serial.println("   SIMULATION STARTING");
  Serial.println("   (Arduino controls pump!)");
  Serial.println("=============================");
  Serial.println("");

  // Step 1: Move to Position A and water
  Serial.println(">> Step 1: Moving to Position A...");
  moveToPosition(positionA);
  waterPlant();

  delay(1000);

  // Step 2: Move to Position B and water
  Serial.println(">> Step 2: Moving to Position B...");
  moveToPosition(positionB);
  waterPlant();

  // Step 3: Sleep
  Serial.println("");
  Serial.println("=============================");
  Serial.println("   SIMULATION COMPLETE");
  Serial.println("   >>> SLEEPING <<<");
  Serial.println("=============================");

  stopMotor();
  pumpOFF(); // Make sure pump is OFF
  digitalWrite(LED_BUILTIN, LOW);
  learningMode = false;
}

void setup() {
  Serial.begin(115200);

  // Motor pins
  pinMode(MOTOR_IN1, OUTPUT);
  pinMode(MOTOR_IN2, OUTPUT);
  pinMode(MOTOR_IN3, OUTPUT);
  pinMode(MOTOR_IN4, OUTPUT);

  // Button pins
  pinMode(BUTTON_A, INPUT_PULLUP);
  pinMode(BUTTON_B, INPUT_PULLUP);
  pinMode(RESET_BTN, INPUT_PULLUP);

  // Pump relay (Arduino direct control)
  pinMode(PUMP_PIN, OUTPUT);
  digitalWrite(PUMP_PIN, RELAY_ACTIVE_LOW ? HIGH : LOW); // Start with pump OFF

  // LED
  pinMode(LED_BUILTIN, OUTPUT);
  digitalWrite(LED_BUILTIN, HIGH);

  Serial.println("");
  Serial.println("=============================");
  Serial.println("  ROTATING TABLE + PUMP");
  Serial.println("  (Skip soil sensor)");
  Serial.println("=============================");
  Serial.println("");
  Serial.println("LEARNING MODE:");
  Serial.println("  HOLD Button A = rotate CW");
  Serial.println("  CLICK Button A = save Position A");
  Serial.println("  HOLD Button B = rotate CCW");
  Serial.println("  CLICK Button B = save Position B");
  Serial.println("");
  Serial.println("After both saved -> Pump runs at each position!");
  Serial.println("");
}

void loop() {
  // === RESET BUTTON - CHECK FIRST (works even in sleep mode!) ===
  if (digitalRead(RESET_BTN) == LOW) {
    Serial.println("");
    Serial.println(">>> RESET! <<<");
    positionA = -1;
    positionB = -1;
    currentPos = 0;
    learningMode = true;
    pumpOFF(); // Make sure pump is OFF
    digitalWrite(LED_BUILTIN, HIGH);

    for (int i = 0; i < 3; i++) {
      digitalWrite(LED_BUILTIN, LOW);
      delay(100);
      digitalWrite(LED_BUILTIN, HIGH);
      delay(100);
    }

    while (digitalRead(RESET_BTN) == LOW)
      delay(10);

    Serial.println("Reset complete. Ready for new positions!");
    Serial.println("");
    return;
  }

  // Sleep mode - do nothing except check reset
  if (!learningMode) {
    delay(100);
    return;
  }

  // === BUTTON A ===
  if (digitalRead(BUTTON_A) == LOW) {
    unsigned long pressStart = millis();
    bool isHold = false;

    while (digitalRead(BUTTON_A) == LOW) {
      if (millis() - pressStart > 300) {
        isHold = true;
        stepMotor(true);
      }
    }
    stopMotor();

    if (!isHold) {
      positionA = currentPos;
      Serial.print(">>> Position A SAVED at step ");
      Serial.println(positionA);

      Serial.print("    A=");
      Serial.print(positionA);
      Serial.print(" B=");
      Serial.println(positionB);

      for (int i = 0; i < 2; i++) {
        digitalWrite(LED_BUILTIN, LOW);
        delay(150);
        digitalWrite(LED_BUILTIN, HIGH);
        delay(150);
      }

      if (positionA != -1 && positionB != -1) {
        Serial.println(">>> BOTH POSITIONS SET! Starting simulation...");
        delay(500);
        runSimulation();
      } else {
        Serial.println(">>> Waiting for both positions to be set...");
      }
    }
    delay(100);
  }

  // === BUTTON B ===
  if (digitalRead(BUTTON_B) == LOW) {
    unsigned long pressStart = millis();
    bool isHold = false;

    while (digitalRead(BUTTON_B) == LOW) {
      if (millis() - pressStart > 300) {
        isHold = true;
        stepMotor(false);
      }
    }
    stopMotor();

    if (!isHold) {
      positionB = currentPos;
      Serial.print(">>> Position B SAVED at step ");
      Serial.println(positionB);

      Serial.print("    A=");
      Serial.print(positionA);
      Serial.print(" B=");
      Serial.println(positionB);

      for (int i = 0; i < 3; i++) {
        digitalWrite(LED_BUILTIN, LOW);
        delay(150);
        digitalWrite(LED_BUILTIN, HIGH);
        delay(150);
      }

      if (positionA != -1 && positionB != -1) {
        Serial.println(">>> BOTH POSITIONS SET! Starting simulation...");
        delay(500);
        runSimulation();
      } else {
        Serial.println(">>> Waiting for both positions to be set...");
      }
    }
    delay(100);
  }

  // === OUTPUT FOR SERIAL PLOTTER (every 500ms) ===
  static unsigned long lastPlotterOutput = 0;
  if (millis() - lastPlotterOutput > 500) {
    lastPlotterOutput = millis();
    // Format: Servo: XX Motor: XXX ON/OFF
    int servoAngle = map(currentPos % 23210, 0, 23210, 0, 180);
    Serial.print("Servo: ");
    Serial.print(servoAngle);
    Serial.print(" Motor: ");
    Serial.print(digitalRead(PUMP_PIN) == (RELAY_ACTIVE_LOW ? LOW : HIGH) ? 255
                                                                          : 0);
    Serial.print(" ");
    Serial.println(digitalRead(PUMP_PIN) == (RELAY_ACTIVE_LOW ? LOW : HIGH)
                       ? "ON"
                       : "OFF");
  }

  delay(10);
}

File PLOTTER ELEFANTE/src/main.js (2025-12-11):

import { SmoothieChart, TimeSeries } from "smoothie";
import "./style.css";

// Get DOM elements
const btnConnectArduino = document.getElementById("connectArduino");
const btnConnectRP2350 = document.getElementById("connectRP2350");
const btnDisconnectAll = document.getElementById("disconnectAll");
const arduinoStatusEl = document.getElementById("arduinoStatus");
const rp2350StatusEl = document.getElementById("rp2350Status");

const currentTemp = document.getElementById("currentTemp");
const currentPot = document.getElementById("currentPot");
const currentServo = document.getElementById("currentServo");
const currentMotor = document.getElementById("currentMotor");
const currentHumidity = document.getElementById("currentHumidity");

// Global variables for dual ports
let arduinoPort = null;
let arduinoReader = null;
let rp2350Port = null;
let rp2350Reader = null;

let latestValues = {
  temp: 0,
  pot: 0,
  servo: 0,
  motor: 0,
  humidity: 0
};
let pumpOn = false;

function makeChart(canvasId, color, minValue, maxValue, label) {
  const chart = new SmoothieChart({
    millisPerPixel: 20,
    interpolation: "linear",
    grid: {
      fillStyle: "#ffffff",
      strokeStyle: "#e0e0e0",
      millisPerLine: 2000,
      verticalSections: 4,
    },
    labels: {
      fillStyle: "#333333",
      fontSize: 12,
    },
    tooltip: true,
    minValue: minValue,
    maxValue: maxValue,
    timestampFormatter: SmoothieChart.timeFormatter,
  });

  const canvas = document.getElementById(canvasId);
  chart.streamTo(canvas, 500);

  const series = new TimeSeries();
  chart.addTimeSeries(series, {
    lineWidth: 3,
    strokeStyle: color,
    fillStyle: color + "20",
  });

  return series;
}

// Create all charts
const sTemp = makeChart("chartTemp", "#e74c3c", -10, 50, "Temperature");
const sPot = makeChart("chartPot", "#3498db", 0, 4095, "Soil Moisture");
const sHumidity = makeChart("chartHumidity", "#8e44ad", 0, 100, "Humidity");
const sServo = makeChart("chartServo", "#2ecc71", 0, 180, "Servo");
const sMotor = makeChart("chartMotor", "#f39c12", 0, 255, "Motor");

// Update charts periodically
setInterval(() => {
  const now = Date.now();
  sTemp.append(now, latestValues.temp);
  sHumidity.append(now, latestValues.humidity);
  sPot.append(now, latestValues.pot);
  sServo.append(now, latestValues.servo);
  sMotor.append(now, latestValues.motor);

  currentTemp.textContent = `Temperature: ${latestValues.temp.toFixed(1)} \u00B0C`;
  currentHumidity.textContent = `Humidity: ${latestValues.humidity.toFixed(0)} %`;
  currentPot.textContent = `Soil Moisture (ADC): ${latestValues.pot} ADC`;
  currentServo.textContent = `Servo Angle: ${latestValues.servo}\u00B0`;
  currentMotor.textContent = `Motor / Pump PWM: ${latestValues.motor} PWM ${pumpOn ? "(ON)" : "(OFF)"}`;
}, 100);

// Connect to Arduino (COM4 typically)
btnConnectArduino.addEventListener("click", async () => {
  try {
    if (!("serial" in navigator)) {
      alert("This browser does not support Web Serial. Use Chrome or Edge.");
      return;
    }

    // Request Arduino port (no filter - let user select any port)
    arduinoPort = await navigator.serial.requestPort();

    await arduinoPort.open({ baudRate: 9600 });

    arduinoStatusEl.textContent = "Connected";
    arduinoStatusEl.className = "status-connected";
    btnConnectArduino.disabled = true;

    readSerialData(arduinoPort, "arduino");
  } catch (err) {
    console.error("Arduino connection error:", err);
    arduinoStatusEl.textContent = "Error";
    arduinoStatusEl.className = "status-disconnected";
  }
});

// Connect to RP2350 (COM7 typically)
btnConnectRP2350.addEventListener("click", async () => {
  try {
    if (!("serial" in navigator)) {
      alert("This browser does not support Web Serial. Use Chrome or Edge.");
      return;
    }

    // Request RP2350 port (generic USB Serial)
    rp2350Port = await navigator.serial.requestPort();

    await rp2350Port.open({ baudRate: 115200 });

    rp2350StatusEl.textContent = "Connected";
    rp2350StatusEl.className = "status-connected";
    btnConnectRP2350.disabled = true;

    readSerialData(rp2350Port, "rp2350");
  } catch (err) {
    console.error("RP2350 connection error:", err);
    rp2350StatusEl.textContent = "Error";
    rp2350StatusEl.className = "status-disconnected";
  }
});

// Disconnect all
btnDisconnectAll.addEventListener("click", async () => {
  if (arduinoReader) {
    await arduinoReader.cancel();
    arduinoReader = null;
  }
  if (arduinoPort) {
    await arduinoPort.close();
    arduinoPort = null;
  }
  arduinoStatusEl.textContent = "Disconnected";
  arduinoStatusEl.className = "status-disconnected";
  btnConnectArduino.disabled = false;

  if (rp2350Reader) {
    await rp2350Reader.cancel();
    rp2350Reader = null;
  }
  if (rp2350Port) {
    await rp2350Port.close();
    rp2350Port = null;
  }
  rp2350StatusEl.textContent = "Disconnected";
  rp2350StatusEl.className = "status-disconnected";
  btnConnectRP2350.disabled = false;
});

async function readSerialData(port, source) {
  const decoder = new TextDecoder();
  let buffer = "";

  while (port && port.readable) {
    const reader = port.readable.getReader();
    if (source === "arduino") arduinoReader = reader;
    else rp2350Reader = reader;

    try {
      while (true) {
        const { value, done } = await reader.read();
        if (done) break;
        if (!value) continue;

        buffer += decoder.decode(value, { stream: true });
        const lines = buffer.split(/\r?\n/);
        buffer = lines.pop() ?? "";

        for (const line of lines) {
          if (!line) continue;
          parseStatusLine(line, source);
        }
      }
    } catch (err) {
      console.error(`Error reading ${source} data:`, err);
    } finally {
      const tail = decoder.decode();
      if (tail) buffer += tail;
      reader.releaseLock();
    }
  }
}
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

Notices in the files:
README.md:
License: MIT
